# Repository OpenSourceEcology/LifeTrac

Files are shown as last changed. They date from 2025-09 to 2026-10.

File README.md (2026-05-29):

# LifeTrac
Skidded Tractor For Everday Use

This repository contains detailed information about each version of the LifeTrac series, including comprehensive documentation extracted from the Open Source Ecology wiki pages.

## Version Folders

Each LifeTrac version has its own folder containing detailed documentation:

* **[LifeTrac I](LifeTrac-I/)** - 2008 - The first prototype with articulated steering
* **[LifeTrac II](LifeTrac-II/)** - Beginning of modular Power Cube design with skid steering
* **[LifeTrac III](LifeTrac-III/)** - Compact design with single loader and quick attach valves
* **[LifeTrac IV](LifeTrac-IV/)** - Enhanced with larger hydraulic motors and Modular Wheel Units
* **[LifeTrac V](LifeTrac-V/)** - Introduction of LifeTrac Construction Set with 4"x4" tubing
* **[LifeTrac VI](LifeTrac-VI/)** - Refined design with fixed loader arm geometry
* **[LifeTrac VII](LifeTrac-VII/)** - First tracked version for bulldozer applications
* **[LifeTrac v16](LifeTrac-v16/)** - (LifeTrac VIII) 2016 - Simplified traction machine design
* **[Microtrac v17.10](Microtrac-v17.10/)** - (LifeTrac IX) Compact modular design
* **[LifeTrac v17.10](LifeTrac-v17.10/)** - 5 Minute Part Replacement focus
* **[LifeTrac v20.12](LifeTrac-v20.12/)** - Latest version with UTU and UWU systems
* **[LifeTrac v25](LifeTrac-v25/)** - Remote control system with LoRa/MQTT communication (Work in Progress)

## Genealogy

* [LifeTrac I](https://wiki.opensourceecology.org/wiki/LifeTrac_I) - 2008 - Articulated steering, 4 wheel drive, wheel chains, dedicated 55 hp diesel engine. Limited roll-over protection.
* [LifeTrac II](https://wiki.opensourceecology.org/wiki/LifeTrac_II) - Began modular Power Cube design. Skid steering with tracks on rubber tires, 4 wheel drive, 2 modular engine units (Power Cubes), 54 hp total, front- and rear-end loaders included.
* [LifeTrac III](https://wiki.opensourceecology.org/wiki/LifeTrac_III) - Same as II but one single (front-end) loader arm. 32 cu in hydraulic motors. Quick attach valves added.
* [LifeTrac IV](https://wiki.opensourceecology.org/wiki/LifeTrac_IV) - Larger hydraulic motors (45 cu in) were used, and Modular Wheel Units were added. Quick connects added to hydraulic controls.
* [LifeTrac V](https://wiki.opensourceecology.org/wiki/LifeTrac_V) - Began using LifeTrac Construction Set - 4"x4" square tubing, and increased modularity of construction. Modular Wheel Units continued.
* [LifeTrac VI](https://wiki.opensourceecology.org/wiki/LifeTrac_VI) - Continued LifeTrac Construction Set. Modular Wheel Units are a robust design feature. Same design, but fixed the loader arm geometry.
* [LifeTrac VII](https://wiki.opensourceecology.org/wiki/LifeTrac_VII) - First tracked version built. Continuing Tractor Construction Set with Bulldozer Development.
* [LifeTrac v16](https://wiki.opensourceecology.org/wiki/LifeTrac_v16) (LifeTrac VIII) - 2016 - Tracked tractor designed purely as a simplified traction machine with 7000 lb of pull.
* [Microtrac v17.10](https://wiki.opensourceecology.org/wiki/MicroTrac_v17.10) (LifeTrac IX) - In use in 2021 but modified to shorter tracks.
* [LifeTrac v17.10](https://wiki.opensourceecology.org/wiki/LifeTrac_v17.10) - Universal Wheel Unit no longer the main drive option to promote 5 Minute Part Replacement.
* [LifeTrac v20.12](https://wiki.opensourceecology.org/wiki/LifeTrac_v20.12) - Built during Summer X 2021. Includes work on UTU and UWU. Test bed for 5 Minute Part Replacement.
* [LifeTrac v25](https://wiki.opensourceecology.org/wiki/LifeTrac_v25) - Remote control system featuring LoRa/MQTT communication for hydraulic operation control. Includes Arduino Opta controller, ROS2 integration, and web-based interface with live camera feed. (Work in Progress)

## Repository Structure

Each version folder contains:
- **README.md** - Comprehensive overview with technical details and historical significance
- **bill_of_materials.md** - Bill of materials information (where available)

The documentation has been extracted and compiled from the [Open Source Ecology wiki](https://wiki.opensourceecology.org) to provide a comprehensive reference for each LifeTrac version.

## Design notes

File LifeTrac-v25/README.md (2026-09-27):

# LifeTrac v25 - Remote Control System

LifeTrac v25 features a comprehensive remote control system with multiple control modes including WiFi/MQTT and direct Bluetooth (BLE) communication for hydraulic operation control.

## Machine Design

LifeTrac v25 is a remotely-operated compact utility loader designed as an open-source alternative sized between a Toro Dingo and a Bobcat. Built using parametric OpenSCAD design, it features modular construction following Open Source Ecology principles.

### Design Overview

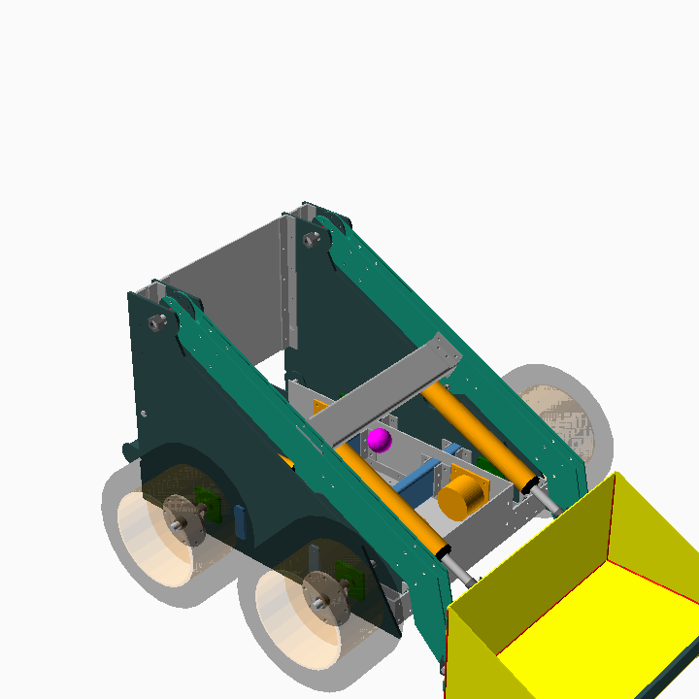
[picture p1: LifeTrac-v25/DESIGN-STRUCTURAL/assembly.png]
LifeTrac v25 Assembly

*3D render of the complete LifeTrac v25 assembly*

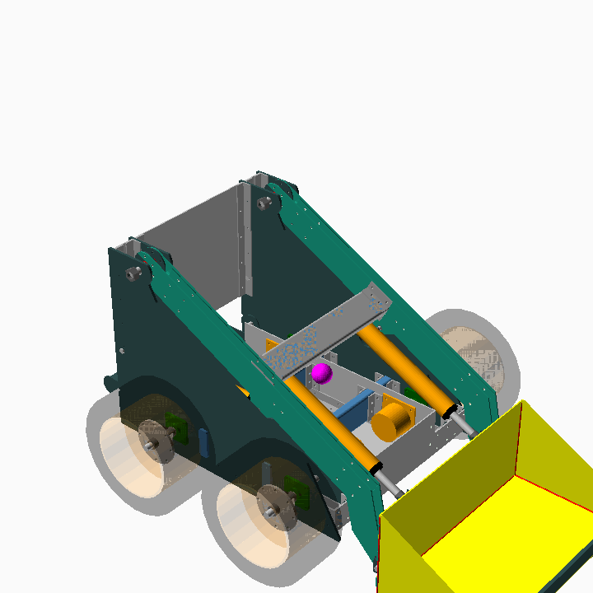
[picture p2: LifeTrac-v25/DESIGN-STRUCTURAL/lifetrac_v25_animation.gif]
LifeTrac v25 Animation

*Animation showing loader arm movement range*

### Key Design Features

- **Modular Construction:** Plate steel, square tubing, and angle iron components for easy fabrication and repair
- **Remote Operation:** No operator seat required, optional standing deck for manual operation
- **Hydraulic Power:** 4 independent wheel motors for all-wheel drive, 2 cylinders for arm lift, 2 for bucket tilt
- **Open Source CAD:** Complete OpenSCAD parametric design files for customization and manufacturing

### Technical Specifications

| Specification | Value (mm) | Value (inches) | Value (meters) |
|---|---|---|---|
| **Overall Width** | 1,200 mm | 47.2" | 1.20 m |
| **Overall Length** | 1,800 mm | 70.9" | 1.80 m |
| **Height to Frame Top** | 1,000 mm | 39.4" | 1.00 m |
| **Ground Clearance** | 150 mm | 5.9" | 0.15 m |
| **Wheel Diameter** | 500 mm | 19.7" | 0.50 m |

### Performance Specifications

| Specification | Value |
|---|---|
| **Hydraulic System Pressure** | 3,000 PSI |
| **Rated Operating Capacity** | See the structural analysis in [STRUCTURAL_ANALYSIS_LOG.md](DESIGN-STRUCTURAL/STRUCTURAL_ANALYSIS_LOG.md) |
| **Drive Configuration** | All-wheel drive (4 hydraulic motors) |
| **Cylinder Bore (Lift)** | 63.5 mm (2.5") |

### Weight Estimate

Machine weight is estimated at **800-1,000 kg (1,760-2,200 lbs)** based on steel construction with:
- 1/4" (6.35mm) plate steel for most components
- 1/2" (12.7mm) plate steel for high-stress areas
- 4"×4"×1/4" square tubing for main frame
- 3"×3"×1/4" square tubing for loader arms

*Note: Weight estimate is a manual calculation based on material specifications. Dimensional specifications in the tables above are automatically extracted from the OpenSCAD design files and updated when the design changes. See [DESIGN-STRUCTURAL/README.md](DESIGN-STRUCTURAL/README.md) for complete design documentation.*

## Features

* **Multiple Control Modes:** switch for MQTT/OFF/BLE mode selection (BLE default)
* **BLE Direct Control:** Direct Bluetooth connection to DroidPad app (no WiFi/broker needed)
* **Remote Joystick Control:** Dual joystick setup for tank steering and hydraulic functions
* **DroidPad Compatible:** Native support for DroidPad via BLE or MQTT
* **WiFi Communication:** Reliable wireless control with MQTT protocol
* **ROS2 Integration:** Control LifeTrac from BeagleBone or any ROS2-enabled device
* **Configurable Flow Control:** Choose between single or dual proportional flow valves via jumper
  - Single valve: Simpler setup, all functions share flow rate (flow is limited by the minimum non-zero joystick input)
  - Dual valve: Independent control, advanced maneuvering with variable turning radius
* **Proportional Flow Control:** Speed regulation based on joystick input intensity
* **Safety Features:** Emergency stop, communication timeout, and fail-safe operation
* **Status Monitoring:** Real-time system status and diagnostics

## Control Scheme

### Tank Steering
- **Left Joystick Y-axis:** Forward/backward movement for both tracks
- **Left Joystick X-axis:** Differential steering (left/right turns)

### Hydraulic Functions  
- **Right Joystick Y-axis:** Arms up/down control
- **Right Joystick X-axis:** Bucket up/down control

### Speed Control
- **Proportional Flow Valve:** Automatically adjusts system speed based on maximum joystick input
- **Deadzone:** 10% deadzone prevents unwanted movements from joystick drift

# Hardware Bill of Materials

## Onboard Controller (LifeTrac)

### Hydraulic Components

| Qty | Item | Description | Unit Price | Total |
|-----|---|---|---|---|
| 4 | Parker Hydraulic Directional Solenoid Valve (D1VW001CNKW) | 21.1 gpm Max Flow Rate, D03 NFPA Size, Three Positions, 12V DC, Closed Center | $314.84  | $1,259.36 |
| | **Purchase:** [Grainger](https://www.grainger.com/product/PARKER-Hydraulic-Directional-Valve-2NMU7) |  |  |  |
| | **Manual:** [Parker D1VW Series Manuals](https://www.manualslib.com/products/Parker-D-1vw-Series-11678625.html) \| [Product Info](https://ph.parker.com/ca/en/product/directional-control-valve-series-d1vw-d1vw-ee/d1vw001cnkw) |  |  |  |
| 8 | Hirschmann DIN Connector (5100-1080000) | Standard hydraulic valve connectors | $7.95 | $63.60 |
| | **Purchase:** [Surplus Center](https://www.surpluscenter.com/Hydraulics/Hydraulic-Valves/Solenoid-Valves/Hirschmann-Connector-5100-1080000-11-2457.axd) |  |  |  |
| |  |  | **Subtotal:** | **$1,322.96** |

### Manifold Subplates

**Option A - For dual proportional valve setup:**

| Qty | Item | Description | Unit Price | Total |
|-----|---|---|---|---|
| 2 | 2 Station D03 Parallel CC Manifold Subplate | For dual valve configuration | $90.00 | $180.00 |
| | | **Purchase:** [Surplus Center](https://www.surpluscenter.com/Hydraulics/Hydraulic-Adapters-Fittings/Subplates-Cover-Plates-Manifolds/2-Station-D03-Parallel-CC-Manifold-Subplate-SFP-10002-9-4070-2.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) | | |
| | | | **Subtotal:** | **$180.00** |

**Option B - For single and no proportional valve setup:**

| Qty | Item | Description | Unit Price | Total |
|-----|---|---|---|---|
| 1 | 4 Station D03 Parallel CC Manifold Subplate | For single or no valve configuration | $183.00 | $183.00 |
| | | **Purchase:** [Surplus Center](https://www.surpluscenter.com/Hydraulics/Hydraulic-Adapters-Fittings/Subplates-Cover-Plates-Manifolds/4-Station-D03-Parallel-CC-Manifold-Subplate-SFP10004-9-4070-4.a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) | | |
| | | | **Subtotal:** | **$183.00** |

### Flow Control Valves

**Option A - Single Valve Configuration (Basic):**

| Qty | Item | Description | Unit Price | Total |
|-----|---|---|---|---|
| 1 | Brand Hydraulics PEFC12-20 Electronically Adjustable Proportional Flow Control Valve | 0-20 GPM, 3000 PSI. For basic configuration | $449.99 | $449.99 |
| | | **Purchase:** [Northern Tool](https://www.northerntool.com/products/brand-hydraulics-electronically-adjustable-flow-control-valve-0-20-gpm-3-000-psi-model-pefc12-20-12-20166) \| [Motion](https://www.motion.com/products/sku/11364850) | | |
| | | **Manual:** [Installation & User Guide (PDF)](https://www.brand-hyd.com/wfdata/files/install/valves/EFC-Installation-Sheet-09-24.pdf) \| [Product Info](https://www.brand-hyd.com/Products/Valves/Flow_Controls/EFC/) | | |
| 1 | Burkert 8605 Type 316532 Flow Valve Controller | PWM control electronics for proportional valves | $319.50 | $319.50 |
| | | **Purchase:** [Valves Direct](https://www.valves-direct.com/burkert-new-products/114143-burkert-316532-type-8605-g-kl-e-f-00-q-b.html) \| [RS Components](https://us.rs-online.com/product/burkert-fluid-control-systems/316532/74474892/) | | |
| | | **Manual:** [Type 8605 Manual (PDF)](https://www.burkert.com/en/content/download/287474/file/MA8605-Manual-EU-EN.pdf) \| [Product Info](https://www.burkert.com/en/products/316532) | | |
| | | | **Subtotal:** | **$769.49** |

**Option B - Dual Valve Configuration (Advanced Maneuvering):**

| Qty | Item | Description | Unit Price | Total |
|-----|---|---|---|---|
| 2 | Brand Hydraulics PEFC12-20 Electronically Adjustable Proportional Flow Control Valve | 0-20 GPM, 3000 PSI. For advanced maneuvering with independent flow control | $449.99 | $899.98 |
| | | **Purchase:** [Northern Tool](https://www.northerntool.com/products/brand-hydraulics-electronically-adjustable-flow-control-valve-0-20-gpm-3-000-psi-model-pefc12-20-12-20166) \| [Motion](https://www.motion.com/products/sku/11364850) | | |
| | | **Manual:** [Installation & User Guide (PDF)](https://www.brand-hyd.com/wfdata/files/install/valves/EFC-Installation-Sheet-09-24.pdf) \| [Product Info](https://www.brand-hyd.com/Products/Valves/Flow_Controls/EFC/) | | |
| 2 | Burkert 8605 Type 316532 Flow Valve Controller | PWM control electronics for proportional valves | $319.50 | $639.00 |
| | | **Purchase:** [Valves Direct](https://www.valves-direct.com/burkert-new-products/114143-burkert-316532-type-8605-g-kl-e-f-00-q-b.html) \| [RS Components](https://us.rs-online.com/product/burkert-fluid-control-systems/316532/74474892/) | | |
| | | **Manual:** [Type 8605 Manual (PDF)](https://www.burkert.com/en/content/download/287474/file/MA8605-Manual-EU-EN.pdf) \| [Product Info](https://www.burkert.com/en/products/316532) | | |
| | | | **Subtotal:** | **$1,538.98** |

*Note: See DESIGN-HYDRAULIC/FLOW_VALVE_CONFIGURATION.md for single vs dual valve configuration details*

### Arduino Controllers

| Qty | Item | Description | Unit Price | Total |
|-----|---|---|---|---|
| 1 | Arduino Opta WiFi | Main controller board | $199.00 | $199.00 |
| | | **Purchase:** [Arduino Store](https://store.arduino.cc/products/opta-wifi) | | |
| | | **Documentation:** [Arduino Opta Docs](https://docs.arduino.cc/hardware/opta) | | |
| 1 | Arduino Pro Opta Ext D1608S | Digital I/O expansion (16 digital inputs, 8 solid state outputs) | $151.00 | $151.00 |
| | | **Purchase:** [Arduino Store](https://store.arduino.cc/products/opta-ext-d1608s) | | |
| 1 | Arduino Pro Opta Ext A0602 | Analog I/O expansion (6 analog inputs, 2 analog outputs) | $229.00 | $229.00 |
| | | **Purchase:** [Arduino Store](https://store.arduino.cc/products/opta-ext-a0602) | | |
| | | | **Subtotal:** | **$579.00** |

## Remote Control Unit

| Qty | Item | Description | Unit Price | Total |
|-----|---|---|---|---|
| 2 | SparkFun Qwiic Joystick (COM-15168) | Dual joystick controllers with I2C interface | $12.50 | $25.00 |
| | | **Purchase:** [SparkFun](https://www.sparkfun.com/products/15168) \| [DigiKey](https://www.digikey.com/en/products/detail/sparkfun-electronics/15168/9953917) | | |
| | | **Guide:** [Hookup Guide](https://learn.sparkfun.com/tutorials/qwiic-joystick-hookup-guide) | | |
| 1 | SparkFun Thing Plus - ESP32 WROOM (USB-C) (DEV-20168) | Remote control microcontroller with WiFi/BLE | $33.73 | $33.73 |
| | | **Purchase:** [SparkFun](https://www.sparkfun.com/products/20168) \| [DigiKey](https://www.digikey.com/en/products/detail/sparkfun-electronics/20168/16688100) | | |
| | | **Guide:** [Product Documentation](https://learn.sparkfun.com/tutorials/sparkfun-thing-plus-esp32-wroom-usb-c-hookup-guide) | | |
| 1 | Enclosure for handheld remote control | Custom or off-the-shelf enclosure | $35.00 | $35.00 |
| 1 | Li-Po battery pack with charging circuit | 3.7V Li-Po battery with USB charging | $20.00 | $20.00 |
| | | | **Subtotal:** | **$113.73** |

## MQTT Broker & Web Controller Infrastructure

| Qty | Item | Description | Unit Price | Total |
|-----|---|---|---|---|
| 1 | Raspberry Pi 4 Model B (4GB) | 4GB+ RAM recommended for Mosquitto MQTT broker and web interface | $55.00 | $55.00 |
| | | **Purchase:** [PiShop](https://www.pishop.us/product/raspberry-pi-4-model-b-4gb/) \| [Authorized Resellers](https://www.raspberrypi.com/products/raspberry-pi-4-model-b/) | | |
| | | **Software:** [Mosquitto MQTT Broker](https://github.com/eclipse-mosquitto/mosquitto) | | |
| 1 | SanDisk Ultra MicroSD Card (32GB) | Class 10, minimum 32GB recommended | $8.99 | $8.99 |
| | | **Purchase:** [Amazon](https://www.amazon.com/micro-sd-card-32gb/s?k=micro+sd-card+32gb) | | |
| 1 | eero 6 Dual-Band Mesh Wi-Fi 6 Router | WiFi 6 mesh router with coverage up to 1,500 sq ft | $89.99 | $89.99 |
| | | **Purchase:** [Best Buy](https://www.bestbuy.com/product/eero-6-dual-band-mesh-wi-fi-6-router-1-pack-white/J39QV832QV) \| [Amazon](https://www.amazon.com/Amazon-eero-6-mesh-Wi-Fi-6-router/dp/B085VM9ZDD) | | |
| | | **Alternative:** [eero 6+ (faster, $139.99)](https://www.amazon.com/Amazon-eero-Wi-Fi-router-newest/dp/B08ZK39NSL) | | |
| 1 | Arducam IMX335 Camera Module (5MP) | Low-light camera for web interface live feed | $33.99 | $33.99 |
| | | **Purchase:** [Amazon](https://www.amazon.com/Arducam-Raspberry-15-15pin-15-22pin-Included/dp/B0FG6W8HC9) \| [RobotShop](https://www.robotshop.com/products/arducam-imx335-mipi-camera-module-rpi) | | |
| | | **Documentation:** [Arducam IMX335 Docs](https://docs.arducam.com/Raspberry-Pi-Camera/Native-camera/5MP-IMX335) | | |
| 1 | Camera cable | 15-pin to 15-pin or 15-pin to 22-pin (included with Arducam) | Included | $0.00 |
| | | | **Subtotal:** | **$187.97** |

---

### Grand Total

| Configuration | Components | Total |
|---|---|---|
| **Base System** (without flow valves, remote, or web infrastructure) | Hydraulic Components + Manifold + Arduino Controllers | **$2,081.96** (Option A) or **$2,084.96** (Option B) |
| **Base + Single Flow Valve** | Base System + 1 Flow Control Valve + 1 Controller | **$2,851.45** (Option A) or **$2,854.45** (Option B) |
| **Base + Dual Flow Valves** | Base System + 2 Flow Control Valves + 2 Controllers | **$3,620.94** (Option A) or **$3,623.94** (Option B) |
| **Complete - Single Valve** | Base + Single Flow Valve + Remote Unit + Infrastructure | **$3,153.15** (Option A) or **$3,156.15** (Option B) |
| **Complete - Dual Valves** | Base + Dual Flow Valves + Remote Unit + Infrastructure | **$3,922.64** (Option A) or **$3,925.64** (Option B) |

**Configuration Notes:**
- **Option A (Manifold)**: 2-station manifold for dual proportional valve setup ($180.00)
- **Option B (Manifold)**: 4-station manifold for single/no proportional valve setup ($183.00)
- **Single Valve**: Basic configuration suitable for most applications
- **Dual Valves**: Advanced maneuvering with independent flow control and variable turning radius

*Note: Prices are subject to change. Check vendor websites for current pricing. Total does not include shipping, taxes, or additional hardware like hydraulic hoses, fittings, and mounting hardware.*

# Software Components

## Arduino Code
- **DESIGN-CONTROLLER/arduino_opta_controller/**: Main controller code for Arduino Opta
- **DESIGN-CONTROLLER/esp32_remote_control/**: Remote control code for ESP32

## Raspberry Pi Web Controller
- **DESIGN-CONTROLLER/raspberry_pi_web_controller/**: Browser-based control with live video feed
  - Live camera streaming from Arducam IMX335 using libcamera
  - Touch-enabled on-screen joysticks for phone/tablet control
  - Keyboard shortcuts for desktop control
  - WebSocket for real-time communication
  - See [DESIGN-CONTROLLER/raspberry_pi_web_controller/README.md](DESIGN-CONTROLLER/raspberry_pi_web_controller/README.md) for setup

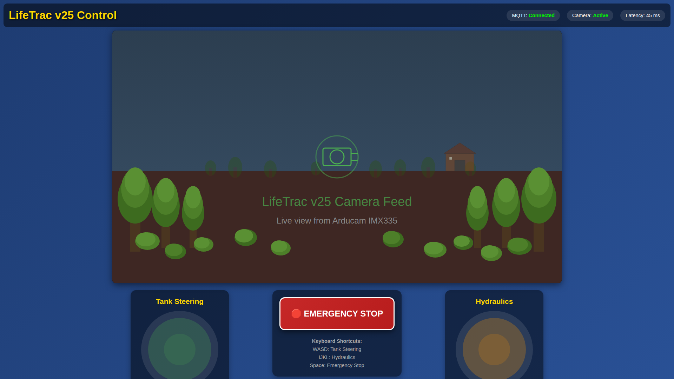
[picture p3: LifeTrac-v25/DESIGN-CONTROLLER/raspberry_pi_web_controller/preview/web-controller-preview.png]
Web Controller Preview

*Browser-based control interface with live camera feed and on-screen joysticks*

## ROS2 Integration
- **DESIGN-CONTROLLER/ros2_bridge/**: ROS2 packages for BeagleBone control via MQTT
  - **lifetrac_msgs/**: Custom ROS2 message definitions
  - **lifetrac_mqtt_bridge/**: Bridge node using mqtt_client package
  - See [DESIGN-CONTROLLER/ros2_bridge/README.md](DESIGN-CONTROLLER/ros2_bridge/README.md) for complete ROS2 setup

## Configuration Files
- **config/**: MQTT broker and WiFi configuration files
- **DESIGN-CONTROLLER/arduino_libraries.txt**: Required Arduino libraries

## Documentation
- **DESIGN-CONTROLLER/INSTALLATION_GUIDE.md**: Complete setup and installation instructions
- **DESIGN-HYDRAULIC/FLOW_VALVE_CONFIGURATION.md**: Proportional flow valve configuration (single vs dual valve)
- **DESIGN-KINEMATICS/README.md**: Motion command semantics — input mapping, differential mixing, ramp profiles, reversal handling, flow budgeting, and the build-variant × motion-primitive matrix
- **DROIDPAD_INTEGRATION.md**: Guide for DroidPad integration via BLE or MQTT
- **DROIDPAD_BLE_SETUP.md**: Step-by-step BLE direct control setup for DroidPad
- **MODE_SWITCH_WIRING.md**: Hardware switch wiring for MQTT/OFF/BLE selection
- **DESIGN-CONTROLLER/WIRING_DIAGRAM.md**: Detailed wiring and connection diagrams
- **DESIGN-HYDRAULIC/HYDRAULIC_DIAGRAM.md**: ASCII hydraulic system diagram showing component layout
- **DESIGN-CONTROLLER/ros2_bridge/README.md**: ROS2 integration and BeagleBone setup guide
- **DESIGN-CONTROLLER/raspberry_pi_web_controller/README.md**: Web interface setup and usage guide

## Testing Tools
- **DESIGN-CONTROLLER/test_scripts/**: MQTT testing and debugging utilities

# Quick Start

## Option 1: DroidPad via BLE (Simplest - Recommended for Mobile)
1. **Program Arduino Opta:** Upload controller code with BLE support
2. **Set Mode:** Set mode switch to BLE position (or leave switch uninstalled for default BLE)
3. **Connect DroidPad:** Open DroidPad app, scan for "LifeTrac-v25" via Bluetooth
4. **Configure:** Set up BLE characteristics using provided UUIDs
5. **Control:** Start controlling immediately - no WiFi/network needed!

For detailed instructions, see [DROIDPAD_BLE_SETUP.md](DESIGN-CONTROLLER/DROIDPAD_BLE_SETUP.md).

## Option 2: Raspberry Pi Web Controller (Best for Fixed Installation)
1. **Set up MQTT Broker:** Install Mosquitto on Raspberry Pi using DESIGN-CONTROLLER/config/mosquitto.conf
2. **Program Arduino Opta:** Upload controller code
3. **Set Mode:** Set mode switch to MQTT position
4. **Install Web Controller:** Run `sudo ./install.sh` in DESIGN-CONTROLLER/raspberry_pi_web_controller/
5. **Connect Camera:** Attach Arducam IMX335 to Raspberry Pi
6. **Access Interface:** Open `http://<raspberry-pi-ip>:5000` in any browser

For detailed instructions, see [DESIGN-CONTROLLER/raspberry_pi_web_controller/README.md](DESIGN-CONTROLLER/raspberry_pi_web_controller/README.md).

## Option 3: ESP32 Handheld Remote Control
1. **Set up MQTT Broker:** Install Mosquitto on Raspberry Pi using DESIGN-CONTROLLER/config/mosquitto.conf
2. **Program Controllers:** Upload Arduino code to Opta and ESP32 boards
3. **Set Mode:** Set mode switch to MQTT position
4. **Configure Network:** Update WiFi credentials and MQTT settings in code
5. **Wire System:** Follow DESIGN-CONTROLLER/WIRING_DIAGRAM.md for all connections
6. **Test System:** Use DESIGN-CONTROLLER/test_scripts/mqtt_test.py for validation

For detailed instructions, see [DESIGN-CONTROLLER/INSTALLATION_GUIDE.md](DESIGN-CONTROLLER/INSTALLATION_GUIDE.md).

## Option 4: ROS2 Control from BeagleBone
1. **Set up MQTT Broker:** Same as above
2. **Program Arduino Opta:** Upload controller code
3. **Set Mode:** Set mode switch to MQTT position
4. **Install ROS2 on BeagleBone:** Follow ROS2 installation guide
5. **Build ROS2 packages:** Build lifetrac_msgs and lifetrac_mqtt_bridge
6. **Launch bridge:** `ros2 launch lifetrac_mqtt_bridge lifetrac_bridge.launch.py`

For detailed ROS2 instructions, see [DESIGN-CONTROLLER/ros2_bridge/README.md](DESIGN-CONTROLLER/ros2_bridge/README.md).

# Safety Features

- **Communication Timeout:** All movement stops if no commands received within 1 second
- **Emergency Stop:** Serial command or communication loss triggers immediate stop
- **Fail-Safe Operation:** Valves return to neutral position on power loss
- **Status Monitoring:** Real-time diagnostics and connection status

# Development Status

✅ **Completed:**
- Arduino Opta controller code with MQTT integration
- ESP32 remote control with dual joystick support  
- Proportional flow control implementation
- Safety systems and emergency stop functionality
- Complete installation and wiring documentation
- MQTT test utilities for debugging
- ROS2 integration packages for BeagleBone control
- Custom ROS2 message definitions for control commands
- Bridge using mqtt_client for ROS2-MQTT communication
- **Raspberry Pi web controller with live video feed and browser-based joysticks**

🔄 **In Progress:**
- Field testing and calibration

# External Links

- [Arduino Opta Documentation](https://docs.arduino.cc/hardware/opta)
- [SparkFun Qwiic Joystick Guide](https://learn.sparkfun.com/tutorials/qwiic-joystick-hookup-guide)
- [Eclipse Mosquitto MQTT Broker](https://mosquitto.org/)
- [Arducam IMX335 Documentation](https://docs.arducam.com/Raspberry-Pi-Camera/Native-camera/5MP-IMX335)
- [Raspberry Pi libcamera Guide](https://www.raspberrypi.com/documentation/computers/camera_software.html)

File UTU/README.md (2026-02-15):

# Universal Track Unit (UTU)

The Universal Track Unit (UTU) is an interchangeable traction module designed to work interchangeably with the Universal Wheel Unit (UWU).

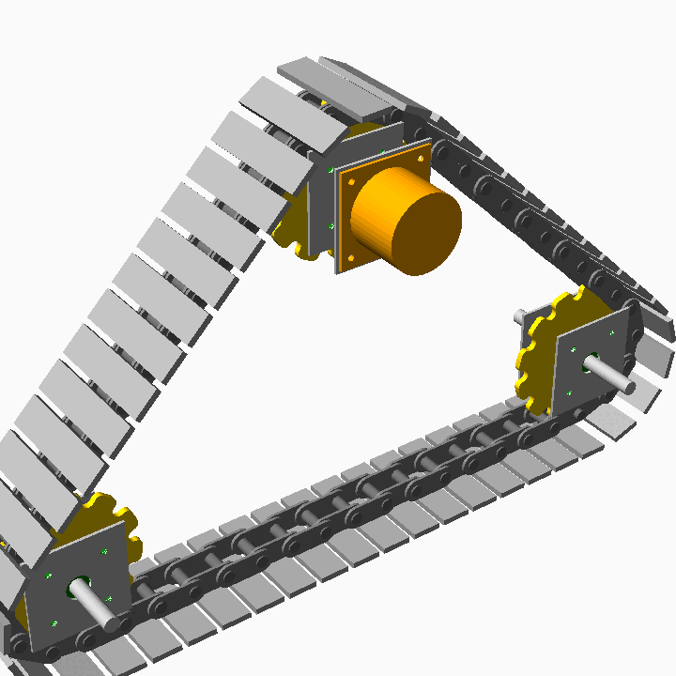
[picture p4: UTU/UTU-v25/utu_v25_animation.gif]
UTU v25 Animation


## References
- [Universal Track Unit Wiki](https://wiki.opensourceecology.org/wiki/Universal_Track_Unit)

## Integration
We want to have the option to use either the UWU or UTU for the LifeTrac v25.

The design goal is to be able to give a coordinate on any future machine and define the three plates and the unit size, so that the UWU or UTU can be adopted for use in place.

## UTU v25 Specifications

The v25 iteration of the UTU is designed with the following parameters (Source: `UTU-v25/utu_v25.scad`):

### Layout
- **Topology:** 3-axis triangular system (configurable via `num_axes`).
- **Bottom Idlers:** 2 idler axes, 4 feet apart (`idler_spacing = 48"`).
- **Drive Axis:** 1 powered axis, 2 feet above idlers, centered horizontally.
- **Front Idler Adjustment:** Automatically shifts along X to make total chain length an integer multiple of chain pitch.

### Structure (shared with UWU)
- **Plates:** 8" x 8" x 0.25" Steel Plates.
- **Bearing Spacing:** 4.0" between bearing plates.
- **Motor Mount to Bearing:** 3.0" spacing.

### Bearing Mounts
- **Bearing Type:** 4-bolt Flange Bearing.
- **Housing:** Ø2.5", 0.75" protrusion, 0.5" flange.
- **Mounting Pattern:** 4-bolt, Ø6.19" BCD, 45° orientation.
- **Center Clearance:** Ø2.00".

### Motor Mount (Drive Axis)
- **Motor Body:** Ø6.0" x 5.0".
- **Motor Flange:** 7.5" x 7.5" Square, 0.5" thick.
- **Motor Shaft:** Ø1.0" x 1.5".
- **Mounting Pattern:** 4-bolt, Ø8.25" BCD, 45° orientation.
- **Coupling:** Ø2.0" x 2.0".

### Drivetrain
- **Shaft:** Ø1.25" x 14.0" length.
- **Shaft Collars:** Ø2.0" x 0.75", sandwiching each sprocket.

### Track Chain
- **Style:** Chainsaw-chain staggered links (alternating inner/outer connector plates).
- **Track Bars (Feet):** 2.5" x 0.5" x 10" steel bar.
- **Connecting Rods:** Ø1.0" steel rods.
- **Chain Pitch:** 3.0" (bar width + 0.5" gap).
- **Rod Hole Clearance:** 1 mm diametral.

### Connector Plates
- **Height:** 2.0" above bar surface.
- **Thickness:** 0.25".
- **Width:** One chain pitch (3.0").
- **Inner Plate Offset:** Derived from 2.0" face-to-face gap.
- **Outer Plate Offset:** Derived from inner offset + 1/8" stagger gap.
- **Rod Pads:** Circular pads (union) at each rod hole location.

### Sprocket
- **Type:** Custom chain sprocket with filleted tooth roots.
- **Teeth:** 12.
- **Pitch Radius:** Derived from chain pitch via `P / (2 × sin(180/N))`.
- **Root Circle:** Sized to sit on track bar surface.
- **Tip Radius:** Pitch radius + rod seat radius.
- **Thickness:** 0.5".
- **Fillets:** Rod radius at tooth roots (offset-based).
- **Phase:** Per-sprocket rotation computed from chain path geometry.

### Chain Path (Parametric)
- **Total Length:** Automatically computed (straight spans + sprocket arc wraps).
- **Link Count:** Rounded to nearest integer (`num_chain_links`).
- **Front Idler Adjustment:** Newton-method shift so chain = integer × pitch.
- **Path Function:** `chain_point(s)` returns `[x, z, angle]` for any cumulative position.
- **Wrap Angles:** Computed per-sprocket from tangent contact geometry.

### CAD Files
- **OpenSCAD:** `UTU-v25/utu_v25.scad` (Parametric source).
- **Gear Library:** `UTU-v25/gears.scad` (chrisspen/gears, CC BY-NC-SA).

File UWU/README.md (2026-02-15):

# Universal Wheel Unit (UWU)

The Universal Wheel Unit (UWU) is a standardized system of bearings and motors mounted to three parallel plates.

## References
- [Universal Wheel Unit Wiki](https://wiki.opensourceecology.org/wiki/Universal_Wheel_Unit)
- [Quick Connect Wheels Wiki](https://wiki.opensourceecology.org/wiki/Quick_Connect_Wheels)

## Integration
We want to have the option to use either the UWU or UTU (Universal Track Unit) for the LifeTrac v25.

The design goal is to be able to give a coordinate on any future machine and define the three plates and the UWU size, so that the UWU or UTU can be adopted for use in place. Both units share the same plate dimensions, bolt patterns, and bearing/motor mounting interfaces.

## UWU v25 Specifications

The v25 iteration of the UWU is designed with the following parameters (Source: `UWU-v25/uwu_v25.scad`):

### Structure
- **Plates:** Three 8" x 8" x 0.25" Steel Plates.
- **Spacing:**
  - Motor Mount Plate to First Bearing Plate: 3.0"
  - First Bearing Plate to Second Bearing Plate: 4.0"

### Motor Mount (Plate 1)
- **Motor Body:** Ø6.0"
- **Motor Flange:** 7.5" x 7.5" Square.
- **Mounting Pattern:** 4-bolt, Ø8.25" Bolt Circle Diameter (4.125" radius), rotated 45° to fit corners.
- **Center Pilot:** Ø2.00"

### Bearing Mounts (Plate 2 & 3)
- **Bearing Type:** 4-bolt Flange Bearing.
- **Housing:** Ø2.5"
- **Mounting Pattern:** 4-bolt, Ø6.19" Bolt Circle Diameter (Derived from QC Wheel fabrication diagrams).
- **Center Clearance:** Ø2.00"

### Drivetrain
- **Shaft:** Ø1.25" x 10.0" Length.
- **Coupling:** Ø2.0" x 2.0" Length connecting Motor Shaft to Main Shaft.

### Compatibility with UTU
The UWU shares its plate dimensions, bolt patterns, bearing mounts, and motor mount interface with the UTU (Universal Track Unit). See `../UTU/README.md` for the track unit specifications.

### CAD Files
- **OpenSCAD:** `UWU-v25/uwu_v25.scad` (Parametric source).
- **FreeCAD Script:** `UWU-v25/generate_uwu_freecad.py` (Generator script).

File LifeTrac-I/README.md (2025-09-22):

# LifeTrac I

**Year:** 2008  
**Alternative Name:** First LifeTrac Prototype  
**Wiki Reference:** [LifeTrac I](https://wiki.opensourceecology.org/wiki/LifeTrac_I)

## Overview

This is the first prototype of the LifeTrac - completed in September, 2008. It was OSE's first attempt to make a riding tractor using articulated steering. The LifeTrac I featured:

- Articulated steering
- 4 wheel drive
- Wheel chains
- Dedicated 55 hp diesel engine
- Limited roll-over protection

## Key Features

- **Steering System:** Articulated steering mechanism
- **Drive System:** 4 wheel drive configuration
- **Traction:** Wheel chains for improved grip
- **Power Plant:** Dedicated 55 hp diesel engine
- **Safety:** Limited roll-over protection

## Historical Significance

The LifeTrac I represents the beginning of Open Source Ecology's modular tractor design journey. This prototype established the foundation for the subsequent development of the LifeTrac series, beginning the exploration of modular, open-source agricultural machinery.

## Status

This is a historical prototype that led to the development of improved versions with enhanced modularity and design features.

## External Links

- [LifeTrac I Blog Post](https://www.opensourceecology.org/lifetrac-continued/)
- [OSE Wiki Page](https://wiki.opensourceecology.org/wiki/LifeTrac_I)

## Next Version

See [LifeTrac II](../LifeTrac-II/README.md) for the next iteration in the series.

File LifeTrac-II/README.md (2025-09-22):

# LifeTrac II

**Alternative Name:** Second LifeTrac Prototype  
**Wiki Reference:** [LifeTrac II](https://wiki.opensourceecology.org/wiki/LifeTrac_II)

## Overview

The LifeTrac II was a departure from the articulated steering design in LifeTrac I to a skid steer design. This version began the modular Power Cube design that became a hallmark of the LifeTrac series. The tractor is powered by 2 Power Cubes and has 2 loaders - both on the front and on the rear of the tractor.

## Key Features

- **Steering System:** Skid steering with tracks on rubber tires
- **Drive System:** 4 wheel drive
- **Power Plant:** 2 modular engine units (Power Cubes), 54 hp total
- **Attachments:** Front-end and rear-end loaders included
- **Design Philosophy:** Beginning of modular Power Cube design

## Design Rationale

The change from articulated to skid steer design was made for several advantages:
- Greater lifting capacities
- Tighter steering in confined spaces  
- Greater flexibility on lift height
- Wider range of tool attachments

**Trade-off:** Skid steer style tractors are much harder on the ground than articulated steering tractors.

## Historical Significance

LifeTrac II marks the beginning of the modular Power Cube design philosophy that would influence all subsequent LifeTrac versions. This represented a major evolution from the single-engine design of LifeTrac I.

## External Links

- [OSE Wiki Page](https://wiki.opensourceecology.org/wiki/LifeTrac_II)

## Navigation

- **Previous:** [LifeTrac I](../LifeTrac-I/README.md)
- **Next:** [LifeTrac III](../LifeTrac-III/README.md)

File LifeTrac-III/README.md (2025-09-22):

# LifeTrac III

**Alternative Name:** Third LifeTrac Iteration  
**Wiki Reference:** [LifeTrac III](https://wiki.opensourceecology.org/wiki/LifeTrac_III)

## Overview

LifeTrac III is the third iteration of the LifeTrac series. It closely matches LifeTrac II, but with significant modifications:
- 18" shorter overall length
- Single (front-end) loader arm instead of dual loaders
- 32 cu in hydraulic motors
- Quick attach valves added

## Key Features

- **Design Base:** Modified LifeTrac II design
- **Size:** Compact design - 18" shorter than LifeTrac II
- **Loader Configuration:** Single front-end loader arm
- **Hydraulic Motors:** 32 cu in hydraulic motors
- **Hydraulic System:** Quick attach valves for improved functionality
- **Construction:** Same skid steer design philosophy as LifeTrac II

## Design Status (as of 2011)

- Several prototypes have been built and tested
- Comprehensive documentation available as part of Civilization Starter Kit DVD v0.01
- Bill of Materials created (completeness under review)
- Testing revealed need for LifeTrac IV to address safety concerns and improve capabilities

## Documentation Resources

The LifeTrac III is extensively documented in the Civilization Starter Kit DVD v0.01:

- 4.1 Tractor Design Rationale, Product Ecology
- 4.2 Tractor Master CAD File
- 4.3 Tractor Bill of Materials
- 4.3-4.4 Tractor Fabrication Manual
- 4.5 Tractor Assembly (full assembly video - 12 min)
- 4.6 Tractor Fabrication Drawings
- 4.7 Tractor User Manual
- 4.8 Quality Control Checklist

## Historical Significance

LifeTrac III represents the refinement of the modular Power Cube concept with improved hydraulic systems and more compact design. The lessons learned from this version directly informed the development of LifeTrac IV.

## External Links

- [OSE Wiki Page](https://wiki.opensourceecology.org/wiki/LifeTrac_III)
- [3D Model on GrabCAD](http://grabcad.com/library/life-traciv-lt3-76inch-long)

## Navigation

- **Previous:** [LifeTrac II](../LifeTrac-II/README.md)
- **Next:** [LifeTrac IV](../LifeTrac-IV/README.md)

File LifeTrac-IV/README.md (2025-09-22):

# LifeTrac IV

**Year:** 2012  
**Alternative Name:** Fourth LifeTrac Iteration  
**Wiki Reference:** [LifeTrac IV](https://wiki.opensourceecology.org/wiki/LifeTrac_IV)

## Overview

LifeTrac IV is the fourth iteration of the LifeTrac series, representing a retrofit of existing LifeTrac III units with significant improvements. This version introduces key innovations that would influence future designs.

## Key Features

- **Frame:** Identical to LifeTrac III
- **Hydraulic Motors:** Larger 45 cu in hydraulic motors (upgraded from 32 cu in)
- **Wheel System:** Modular Wheel Units with Quick Connect Wheels
- **Loader Arms:** Bent Loader Arms for improved geometry
- **Hydraulic Controls:** Quick connects added to hydraulic controls
- **Load Capacity:** Additional load carrying capacity from rear weight addition

## Major Improvements from LifeTrac III

### 1. Quick Connect Wheels
- Modular wheel attachment system
- Improved maintenance and part replacement
- Enhanced field serviceability

### 2. Bent Loader Arms
- Improved loader arm geometry
- Better loading and lifting characteristics
- Enhanced operational efficiency

### 3. Larger Hydraulic Motors
- Upgraded from 32 cu in to 45 cu in hydraulic motors
- Increased power and torque capability
- Better performance under load

### 4. Quick Connect Hydraulics
- Quick connects added to hydraulic controls
- Simplified operation and maintenance
- Enhanced modularity

## Development History

- **Last Updated:** September 9, 2012
- **Design Assistance:** GrabCAD community helped with wheel redesign
- **International Application:** Guatemala Team built LifeTrac IV with Power Cube system
- **Design Philosophy:** Retrofit approach to upgrade existing LifeTrac III units

## Historical Significance

LifeTrac IV introduced the Modular Wheel Units concept and Quick Connect systems that became fundamental to the LifeTrac philosophy of modular, serviceable design. The bent loader arms solved geometry issues from previous versions.

## External Links

- [OSE Wiki Page](https://wiki.opensourceecology.org/wiki/LifeTrac_IV)
- [GrabCAD Wheel Design Challenge](http://grabcad.com/challenges/lifetrac-quick-connect-wheels)
- [Guatemala Build Log](https://wiki.opensourceecology.org/wiki/Guatemala_Log)

## Navigation

- **Previous:** [LifeTrac III](../LifeTrac-III/README.md)
- **Next:** [LifeTrac V](../LifeTrac-V/README.md)

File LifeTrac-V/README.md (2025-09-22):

# LifeTrac V

**Alternative Name:** Fifth LifeTrac Iteration  
**Wiki Reference:** [LifeTrac V](https://wiki.opensourceecology.org/wiki/LifeTrac_V)

## Overview

LifeTrac V represents a significant milestone in the LifeTrac series as it began using the LifeTrac Construction Set philosophy. This version marked the standardization of construction methods and increased modularity that would define future LifeTrac designs.

## Key Features

- **Construction Standard:** Began using LifeTrac Construction Set with 4"x4" square tubing
- **Modularity:** Increased modularity of construction
- **Wheel System:** Modular Wheel Units continued from LifeTrac IV
- **Design Philosophy:** Standardized construction methods for easier replication

## Innovation: LifeTrac Construction Set

The introduction of the LifeTrac Construction Set was a major advancement:
- **Material Standard:** 4"x4" square tubing as primary structural element
- **Modularity:** Enhanced modular design for easier assembly and maintenance
- **Standardization:** Consistent construction methods across components
- **Replicability:** Simplified design for easier reproduction by other builders

## Design Evolution

LifeTrac V built upon the successful innovations of LifeTrac IV while introducing:
- Standardized construction methodology
- Enhanced modularity through the Construction Set approach
- Continued use of Modular Wheel Units
- Improved design consistency

## Historical Significance

This version established the LifeTrac Construction Set philosophy using 4"x4" square tubing, which became a foundational element for subsequent designs. The focus on modular construction made the design more accessible to builders worldwide.

## External Links

- [OSE Wiki Page](https://wiki.opensourceecology.org/wiki/LifeTrac_V)

## Navigation

- **Previous:** [LifeTrac IV](../LifeTrac-IV/README.md)
- **Next:** [LifeTrac VI](../LifeTrac-VI/README.md)

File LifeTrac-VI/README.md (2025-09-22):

# LifeTrac VI

**Alternative Name:** Sixth LifeTrac Iteration  
**Status:** In active use (as of 2019)  
**Wiki Reference:** [LifeTrac VI](https://wiki.opensourceecology.org/wiki/LifeTrac_VI)

## Overview

LifeTrac VI continued the LifeTrac Construction Set philosophy established in LifeTrac V. This version represents a refinement of the modular design with robust Modular Wheel Units as a key design feature. A significant improvement was made to the loader arm geometry, fixing issues from previous versions.

## Key Features

- **Construction:** Continued LifeTrac Construction Set with 4"x4" square tubing
- **Modularity:** Modular Wheel Units as a robust design feature
- **Loader Arms:** Fixed loader arm geometry from previous versions
- **Design:** Same overall design as LifeTrac V with improved geometry
- **Status:** Proven design in active use

## Design Improvements

### Loader Arm Geometry
- Fixed loader arm geometry issues from previous versions
- Improved loading and operational characteristics
- Enhanced reliability and performance

### Modular Wheel Units
- Robust implementation of the modular wheel concept
- Reliable field performance
- Proven design for long-term use

## Operational Status

As of 2019, LifeTrac VI remains in active use, demonstrating the reliability and effectiveness of the design improvements made in this iteration.

## Historical Significance

LifeTrac VI represents the maturation of the LifeTrac Construction Set approach with proven modular components. The successful resolution of loader arm geometry issues in this version established design principles that influenced future developments.

## External Links

- [OSE Wiki Page](https://wiki.opensourceecology.org/wiki/LifeTrac_VI)
- [LifeTrac VI Video](https://www.youtube.com/embed/gXP01bjIwHo)

## Navigation

- **Previous:** [LifeTrac V](../LifeTrac-V/README.md)
- **Next:** [LifeTrac VII](../LifeTrac-VII/README.md)

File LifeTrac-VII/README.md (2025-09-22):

# LifeTrac VII

**Alternative Name:** First Tracked Version / Bulldozer  
**Wiki Reference:** [LifeTrac VII](https://wiki.opensourceecology.org/wiki/LifeTrac_VII) (redirects to [Bulldozer](https://wiki.opensourceecology.org/wiki/Bulldozer))

## Overview

LifeTrac VII represents a major departure from previous wheeled designs as the first tracked version built in the LifeTrac series. This version continued the Tractor Construction Set philosophy but adapted it for tracked bulldozer development, marking the beginning of specialized earth-moving capabilities within the LifeTrac ecosystem.

## Key Features

- **Track System:** First tracked version in the LifeTrac series
- **Construction:** Continued Tractor Construction Set with 4"x4" square tubing
- **Purpose:** Specialized for earth-moving and bulldozer applications
- **Design Philosophy:** Integration of tracked mobility with modular construction

## Design Evolution

### Tracked Mobility
- Excellent ground hold and mobility through rough terrain
- Wide tracks distribute weight over large area
- Prevents sinking in sandy or muddy ground
- Enhanced traction for heavy-duty applications

### Earth-Moving Capabilities
- High-traction, earth-moving functionality
- Suitable for building ponds, berms, and other earthworks
- Road building and land clearing applications
- Integration with bulldozer blade systems

## Technical Specifications

- **Base:** Tractor Construction Set foundation
- **Mobility:** Track-based system for enhanced traction
- **Applications:** Earth-moving, bulldozing, heavy traction work
- **Design:** Lower torque variant with additional weight for stability

## Product Ecology

LifeTrac VII integrates with other GVCS components:
- **Steel:** Produced with Induction Furnace
- **Parts:** Fabricated with CNC Torch Table  
- **Assembly:** Constructed with Welder
- **Base:** Built on Tractor platform

## Historical Significance

LifeTrac VII marked the expansion of the LifeTrac concept beyond traditional tractor applications into specialized earth-moving equipment. This diversification demonstrated the flexibility of the modular construction approach.

## External Links

- [OSE Wiki Page](https://wiki.opensourceecology.org/wiki/LifeTrac_VII)
- [Bulldozer Specification](https://wiki.opensourceecology.org/wiki/Bulldozer_Specification)

## Navigation

- **Previous:** [LifeTrac VI](../LifeTrac-VI/README.md)
- **Next:** [LifeTrac v16](../LifeTrac-v16/README.md)

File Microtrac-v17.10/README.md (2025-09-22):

# Microtrac v17.10

**Alternative Name:** LifeTrac IX  
**Status:** In use in 2021 but modified to shorter tracks  
**Wiki Reference:** [MicroTrac v17.10](https://wiki.opensourceecology.org/wiki/MicroTrac_v17.10)

## Overview

Microtrac v17.10 (also referred to as LifeTrac IX) represents a compact, modular tracked tractor design optimized for versatility and modularity. This version was in active use as of 2021 but was modified to use shorter tracks for improved maneuverability. The design emphasizes the principles of Distributive Enterprise and lifetime design philosophy.

## Key Specifications

### Power System
- **Power Cube:** 16-27 hp as needed (variable configuration)
- **Modularity:** Uses Power Cube system for flexible power management

### Track System
- **Tracks:** 1/2" x 2" steel bar welded track construction
- **Modification:** Modified to shorter tracks (as of 2021 usage)
- **Design:** Robust track system for enhanced traction

### Construction
- **Frame:** 1/4" x 4" perforated steel tubing
- **Shafts:** 3" shafts for wheels and loader arm
- **Philosophy:** Open source design for Distributive Enterprise

### Functionality
- **Productivity:** Full capacity for quick tool attachment
- **Hydraulics:** Hydraulic takeoff to implements on the loader
- **Flexibility:** Multi-function capability through modular attachments

## Technical Features

### Licensing
- **Compliance:** OSHWA and OSI compliant
- **Licenses:** CC-BY-SA-4.0 International, GPLv3, DIN SPEC 3105
- **Philosophy:** Lifetime design approach

### Development Status
- **Stage:** Prototype 2 (Near product release)
- **Dependency:** Pending Universal Track Unit completion
- **Documentation:** See Tractor Construction Set 2017 for design details

## Design Philosophy

Microtrac v17.10 embodies several key principles:
- **Open Source:** Fully open design for global replication
- **Modular:** Component-based design for flexibility
- **Distributive Enterprise:** Designed for distributed manufacturing
- **Lifetime Design:** Built for long-term serviceability and upgradeability

## Related Projects

- **Universal Track Unit:** Key dependency for product completion
- **Tractor Construction Set 2017:** Detailed design documentation
- **Power Cube System:** Modular power system integration

## Historical Significance

This version demonstrates the evolution towards compact, highly modular designs that maintain full functionality while being more accessible for smaller operations and distributed manufacturing.

## External Links

- [OSE Wiki Page](https://wiki.opensourceecology.org/wiki/MicroTrac_v17.10)
- [Tractor Construction Set 2017](https://wiki.opensourceecology.org/wiki/Tractor_Construction_Set_2017)
- [LifeTrac Genealogy](https://wiki.opensourceecology.org/wiki/Lifetrac_Genealogy)

## Navigation

- **Previous:** [LifeTrac v16](../LifeTrac-v16/README.md)
- **Next:** [LifeTrac v17.10](../LifeTrac-v17.10/README.md)

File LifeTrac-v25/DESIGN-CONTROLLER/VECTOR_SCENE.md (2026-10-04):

# LifeTrac v25: Vector Scene mode (VS1) design

> **Status (2026-09-23): design proposal, not implemented.** Rebased on `origin/main` at `d3751286` (2026-09-15), the tree that carries the Murata L072 radio, the strict image path and the FHSS bench campaign. The decisions D-VS1 to D-VS9 (D-VS3 and D-VS3a withdrawn) are proposed and need OSE sign-off; they are listed in [DECISIONS.md](DECISIONS.md#vector-scene-mode--proposed-pending-ose-sign-off). The Vector Lab page ([§8](#8-vector-lab-base-website-live-canvas-input)) needs no radio and can be built first.
>
> **Document roles.** This document is the source of truth for *what to build*. The research and review record, which covers *why*, is [../AI NOTES/2026-09-22_Vector_Scene_Research_ClaudeOpus5_5_v1_0.md](../AI%20NOTES/2026-09-22_Vector_Scene_Research_ClaudeOpus5_5_v1_0.md). It holds the prior-art survey with sources, the current-stack code findings, the FHSS campaign summary, the three competing proposals and how they were scored, and the adversarial-review record.
>
> **Relationship to the shipped pipeline.** VS1 is a new per-frame **codec** inside the existing `TileDeltaFrame` (`codec = 6`) and a new **encode mode** (`EncodeMode.VECTOR = 9`), selected exactly like `mono_g4` is today. It rides the strict image path unchanged: `camera_service.py` → MQTT `cmd/image_frame` → `image_tx_daemon.py` → L072 → air → base L072 → `image_rx_daemon.py` → MQTT `video/tile_delta` → `web_ui.py` → `/ws/state`. Nothing in the L072 firmware changes for the codec itself (Phases 1–3); the optional rung switch of D-VS8 (§4.6) is the one part of this proposal that needs L072 work, and the H7 changes only for the optional S1/S3 pose sources (§5.3). The April plan in [IMAGE_PIPELINE.md](IMAGE_PIPELINE.md) (topic `0x29`, wireframe bitmap, 25 ms fragment cap) is superseded by the shipped path; see [§1](#1-summary-and-design-principles).

---

## 0. Overview

### 0.1 The problem

The image link's bottom rung today is `mono_g4`: a 1-bit Floyd–Steinberg dither per 32×32 tile, zlib-packed (`firmware/tractor_x8/camera_service.py:617-641`). It is honest and cheap, but it is still a **tile** codec:

- A tile costs at least 14 B, and 130 B when dither noise defeats zlib (`camera_service.py:617-641`, `base_station/image_pipeline/codec_decode.py:56-84`). A 243 B frame therefore carries at most 16 of the 96 tiles (225 B after header and bitmap), and a single tile when dither noise defeats zlib, so the operator sees the picture arrive as a rotation of patches over several frames.
- Every frame is a train of tile blobs; a whole-canvas refresh is a keyframe train, and the self-heal keyframe requests chasing lost tiles are what broke the FHSS follower on the bench (222 base `REQ_KEYFRAME` sends, 62.8 % loss, `bench-evidence/RS_12_12_fhss_validation_2026-09-12/RESULTS.md:109-135`).

VS1 sends the **whole frame as geometry** in **one fragment**: horizon, sky and ground gradients, large regions as polygons in their measured colours, trees as ellipses, and edge lines. Shapes keep persistent IDs, so a static scene costs almost nothing and a pan costs one group-shift record. There are no keyframe trains, no keyframe requests and no tiles to lose. It is the mode the system drops to when the signal is degraded and the tile modes are failing, so it carries its own degradation ladder (§4.5): shorter frames, more repeats and less detail as loss rises, with no acknowledgement traffic.

### 0.2 What the operator sees

When VECTOR is the active encode mode, the console camera panel shows a stylised live picture instead of photographic tiles:

- **Sky and ground** as two smooth gradients in the measured colours, split by the real horizon, with a tree-line profile along it.
- **Large regions** as polygons filled with their measured mean colour and a simple gradient: the near field, the track, a shed wall.
- **Isolated trees and shrubs** as coloured ellipses.
- **Edge lines** for ruts, fences, structures and overhead wires.
- **Hatched "unknown" areas** (HOLE records): holes the tractor has reported inside a region but not yet described.
- **Dashed "UNCLASSIFIED" boxes** for anything unusual in the tractor's path, drawn above all scene layers and the self-model.
- **The tractor's own hood**, drawn in outline at the base (from the OpenSCAD model once the camera is calibrated; as the hand-drawn mask outline before that). The hood is normally masked and not transmitted. The loader arm is drawn too if an arm sensor is fitted.
- **Honesty cues:** a banner that raw mode cannot hide ("VECTOR — NOT CAMERA PIXELS · age · loss"), per-shape age styling, and a "SAFETY DETECTOR: NO PIXELS" chip.

The whole worked example scene of §3.6 (23 records, 129 B) fits in **one frame** at either radio profile. Later frames add polygon vertices, holes and fine detail while the scene is static, and a 21-bit group shift moves every shape when the tractor pans.

| Radio profile | VS body per frame | Records per frame (est.) | Worked scene |
|---|---|---|---|
| p1 FHSS (BW250) | 197 B | 1,563 bits ≈ 21–35 records | 1 frame, 545 bits spare |
| p2 DTS (BW500) | 237 B | 1,883 bits ≈ 25–43 records | 1 frame, 865 bits spare |

### 0.3 How it flows

```mermaid
flowchart LR
  CAM["Camera 384x256, 2 fps"] --> EXT["camera_service: extract layers<br/>M, L0-L4 at 96x64 / 192x128"]
  EXT --> TMP["match to live shapes<br/>(T: keep IDs, shift, confirm)"]
  TMP --> PACK["rank by value per bit,<br/>pack ONE fragment (P)"]
  PACK -->|"MQTT cmd/image_frame"| TXD["image_tx_daemon<br/>pacing, single fragment"]
  TXD -->|"L072, FHSS slot or DTS"| RXD["image_rx_daemon<br/>reassemble, republish"]
  RXD -->|"MQTT video/tile_delta"| STORE["web_ui: VectorSceneStore<br/>epochs, ages, badges"]
  SM["self-model<br/>CAD + calibration + pose"] --> PUB
  STORE --> PUB["StatePublisher<br/>/ws/state snapshot"]
  PUB --> BR["browser: vector_renderer.js<br/>+ self_model_overlay.js"]
  LAB["Vector Lab worker<br/>same codec, live canvas input"] -.->|"lab/* topics only"| LABUI["/vector_lab page"]
```

Paint order, from bottom to top:

```
 11  banner "VECTOR — NOT CAMERA PIXELS"          (inside the vector canvas; raw mode cannot hide it)
 10  staleness styling + badges
  9  detections
  8  corridor anomalies (dashed, "UNCLASSIFIED")  (always above the self-model)
  7  self-model (hood outline; sensed arm)        (never opaque over transmitted pixels)
  6  L3 edges (ruts, fences, structures, overhead lines)
  5  L4 detail
  4  L2 trees / shrubs (ellipses)
  3  HOLE hatches
  2  L1 masses (polygons + gradient)
  1  L0 sky / ground gradients + skyline      <- first to arrive
```

### 0.4 How the original ideas map to the design

| Idea | Where it lives in this design |
|---|---|
| Convert everything in the frame to polygons | L1 masses. POLY records with 3–10 vertices; detail is added by INSERT records (§2.5, §3.3). |
| A simple colour gradient matching the average colour | FILL uses the measured mean colour (RGB444, or a palette slot only when within ΔE ≤ 4) plus an optional least-squares linear gradient (§3.3). Colours are never invented (principle 4). |
| Sky and ground as the first layer | L0 HZN record: 42–58 bits, the first record of every new epoch. Later frames send a 15-bit residual (§2.4). |
| More detail as bandwidth allows | Records are ranked by error reduction per bit (CELF), so a frame cut short still holds the best picture for its bytes (§2.9). While the scene is static, spare bits add vertices and detail (§4.3). |
| Trees and shrubs as basic shapes with varying detail | L2 TREE/SHRUB ellipses of 34–51 bits. A merged tree line becomes SKYLINE. Trunks are drawn only when the lens is zoomed in enough to resolve them (§2.6). |
| A 3D model of the tractor's own parts at the base | §5. The OpenSCAD model is exported to a visualisation-only model, then calibrated. The hood is masked on the tractor and costs 0 bits. The arm is posed from a sensor (S1). Vision and valve estimates are Lab-only and clearly labelled. The bucket is never masked. |
| Don't re-send the same vectors | Persistent shape IDs with UPD, UCOL, DEL and CONFIRM records. GSHIFT and GZOOM move whole groups. IMU horizon prediction happens at the base (§4). |
| Other optimizations | §9. |
| Testable on the base station website | Vector Lab (§8): the live canvas at both profile budgets side by side, with per-layer bit bars, loss simulation, a hex frame scrubber and golden-fixture export. |

### 0.5 Reading guide

| If you are… | Read |
|---|---|
| Deciding whether to adopt this | §0, §1 (budget), §4.5 (degraded-signal operation), §6 (mode and policy), §10 (blockers), §11 (decisions and roadmap) |
| Building the Vector Lab (Phase 1) | §2, §3, §7.2, §7.5, §8 |
| Integrating on the strict path (Phase 2) | §3.1, §6, §7 |
| Working on the self-model (Phase 3) | §5, and CALIBRATION.md §6 once it is written |
| Implementing the modem-rung switch on the L072 and the daemons (D-VS8) | §4.5.6, §4.6, §7.4 |

---

## Conventions

**Path key.** `DC/` = `LifeTrac-v25/DESIGN-CONTROLLER/`, `bs/` = `DC/base_station/`, `x8/` = `DC/firmware/tractor_x8/`, `DS/` = `LifeTrac-v25/DESIGN-STRUCTURAL/`, `BE/` = `DC/bench-evidence/`.

- **Estimates.** Anything marked *(est.)* has not been measured.
- **Computed figures.** Airtimes come from read-only runs of `bs/lora_proto.py` (`lora_time_on_air_ms`, `max_image_fragment_body`) at `PHY_IMAGE_BW250` (p1 FHSS) and `PHY_IMAGE_BW500` (p2 DTS), SF7/CR4-5/preamble 8 (`bs/lora_proto.py:150-151`), including the 8 B hop header and the 4 B fragment header. Bit packing and footprint figures come from stdlib Python.
- **Review status.** The first draft (2026-09-22) was written against a checkout from 2026-05-01 and reviewed adversarially against that stack (3 blockers, 34 major, 23 minor issues, all resolved). It was then rebased on the 2026-09-15 tree, which replaced the budget, transport, mode and integration sections. The layer model, record set, temporal rules, self-model and Lab carried over. The per-issue dispositions are in the appendix of the [research note](../AI%20NOTES/2026-09-22_Vector_Scene_Research_ClaudeOpus5_5_v1_0.md#appendix-b-adversarial-review-dispositions).

---

## 1. Summary and design principles

### What changes

A new per-frame codec and encode mode on the shipped strict image path:

| Layer | Content |
|---|---|
| L0 | Horizon, with sky and ground as vertical gradients in the measured mean colours, plus a skyline/treeline profile |
| L1 | Large regions as polygons, each with its measured mean colour and an optional linear gradient. Holes are declared, never silently painted over. |
| L2 | Isolated trees and shrubs as ellipses |
| L3 | Edge polylines, including overhead lines. The "edges only" view is L3 with fills toggled off. |
| L4 | Residual detail |

- Every shape has a persistent ID, and **every frame is one fragment that decodes on its own**.
- The tractor never spends bits on its hood, and optionally on its arm members. The base draws them from a CAD self-model at a pose whose source is always labelled.
- The bucket and cutting edge are **never masked** (§5).
- The `0x29 video/wireframe` topic, the 12,293 B edge bitmap in `x8/x8_image_pipeline/encode_wireframe.py` and `bs/image_pipeline/wireframe_render.py` are dead code on the strict path (no importers outside `bs/tests/test_image_pipeline.py`); VS1 replaces the idea, not the code path.

### Budget (computed)

The strict path sends image fragments in plaintext: an 8 B hop-sync header, a 4 B fragment header (`0xFE | frag_seq | frag_idx | total−1`, `bs/lora_proto.py:819-876`), and up to 243 B of payload (the 247 B `TX_FRAME_BODY_MAX` includes the fragment header, `bs/lora_proto.py:835-836`; the 170 ms cap trims it to 203 B at BW250). There is no KISS and no AES-GCM on this path (`x8/image_tx_daemon.py:36-42`, `bs/image_rx_daemon.py:12-14`). The per-fragment airtime cap is 170 ms (`LIFETRAC_FRAG_AIR_CAP_MS`, `bs/lora_proto.py:837`); the April 25 ms cap was dropped for image traffic (TODO.md RS-9.7).

| Profile | Fragment body | On air | Airtime | VS body (body − 6 B `TileDeltaFrame` header) | Record bits (body × 8 − 13) |
|---|---|---|---|---|---|
| p1 `FCC_15_247_FHSS_50CH_BW250` | 203 B | 215 B | 169.1 ms, one per 200 ms slot | **197 B** | **1,563** |
| p2 `FCC_15_247_DTS_BW500` | 243 B | 255 B | 99.9 ms | **237 B** | **1,883** |

Sources: `x8/image_tx_daemon.py:308` (`_FRAG_BODY_BY_PROFILE`), `SETTINGS_REFERENCE.md` §2.1, `CONTROL_PLANE_DESIGN.md:101`.

- The `TileDeltaFrame` byte budget covers the whole wire payload including its header (`x8/camera_service.py:1066-1075`), and the live budget arrives on the retained `tractor/link_budget` topic as one fragment (`x8/image_tx_daemon.py:435, 1054-1088` → `x8/camera_service.py:824-841`). VS1 sizes every frame to that budget.
- Airtime is paced by time-on-air (`x8/image_tx_daemon.py:355-411`, 0.92 headroom), so a short frame really is cheaper: a 12 B VS body costs 18.0 ms at DTS (36.0 ms at FHSS), a full frame 99.9 ms (169.1 ms). Airtime moves in 3.5 B / 1.28 ms steps at BW500 (2.56 ms at BW250), so bodies of 12–15 B all cost the same (18.0 ms at DTS, 36.0 ms at FHSS).
- At the default 2 fps (`x8/camera_service.py:109`) a full VS frame uses 20 % of DTS airtime and 34 % of FHSS airtime (2 of every 5 slots). A static scene converges to CONFIRM/DIGEST-only frames of a few bytes.

**What this replaces.** The first draft of this document (written against the 2026-05-01 checkout) budgeted 10 B per LoRa frame under a 25 ms cap with 28 B of GCM and KISS framing per frame. None of that exists on the strict path. The measured link gives 699–812 B/s on FHSS and 1.75–2.0 KB/s on DTS (`TODO.md:202-210`; `BE/FW_BATCH1_acceptance_2026-07-30/RESULTS.md:86`; `TODO.md:458-461`, tractor-side), so a VS frame is a single fragment with room to spare, and the design's value moves from "fit in 10 bytes" to **"one fragment per frame, no keyframe trains, honest at the floor"**.

### Principles

1. **Frame-atomic and idempotent.**
   - One fragment per frame; no multi-fragment trains, so no penultimate-fragment loss and nothing to reassemble.
   - Defines are absolute. UPD, GSHIFT, GZOOM and GAIN are *cumulative since epoch start* rather than chained deltas. INSERT is addressed against the immutable define, not the current vertex list.
   - The base applies each **field** (geometry, offset, colour) last-writer-wins by capture time.
   - Loss removes or ages content and never corrupts geometry. Design target: at least 12 % frame loss (the FHSS legs measured 2.1 % with a quiet command plane, `BE/RS_12_12_fhss_validation_2026-09-12/RESULTS.md:90-100`, and 10.5–20.9 % under the keyframe-storm camera load, `BE/RS_12_15_clock_authority_2026-09-14/RESULTS.md:300-352`).
2. **Every record describes the current capture.** The tractor re-measures before it re-sends anything: repeat-once and the carousel re-verify each shape against the newest capture (§4). A frame's age nibble is therefore true for every record in it, as C6 requires (`DC/IMAGE_PIPELINE.md:33`).
3. **Embedded order.**
   - Records are ranked by weighted ΔD per bit (CELF lazy greedy, §2) against a mirror of the base display.
   - Weights: 0 on the self-mask; ×3 in the path corridor and for overhead-line candidates; ×0.5 in the rest of the sky.
   - A frame cut short by the budget still leaves the best picture for its bytes.
4. **Measure, don't invent, and disclose omissions.**
   - Every colour is a measured mean. A palette slot is used only when it is within ΔE76 ≤ 4 of that mean.
   - Every shape comes from real pixels. Extrapolated content is PREDICTED (4); CAD content is MODEL (8).
   - The scene is a lossy *summary*. Objects can be missing, so the UI publishes the minimum-object-size table (§2.3), the "N detected / M shown" count, and hatched HOLE and NOT-TRANSMITTED regions.
5. **The base decides and the browser draws** (C5, `DC/IMAGE_PIPELINE.md:32`).
   - One pure-stdlib codec is shared by the tractor, the base store and the Lab (`bs/image_pipeline/vector_scene/`, deployed to the tractor next to `lora_proto` by the harness push list).
   - The browser receives only JSON.
6. **Supervisory tier; no safety claim.**
   - VECTOR is a "look, then move" view. **v25 has no working person detector.** Both `x8/x8_image_pipeline/detect_nanodet.py` backends return `[]`, and no tractor code emits `CMD_PERSON_APPEARED`. The base R6 detector gets no fresh pixels in VECTOR.
   - The console therefore shows "SAFETY DETECTOR: NO PIXELS". The speed cap (§6) applies once the hydraulic drive plane is on air; today no ControlFrame has flown and the E-stop is the 200 ms deadman ("stop by absence").
7. **No keyframe trains.** An epoch start is one frame (an absolute HZN — ABS, or NO_HORIZON — plus LAYER_CLEAR). Repair is level-triggered inside the next scheduled frame, never by a request that grows the load it responds to. This is the same conclusion the bench reached for tiles: the self-heal keyframe request was net harmful and was replaced by the `0x6C` stale-tile report (`TODO.md:136-140`).
8. **Same radio profile as everything else.** Image frames and base commands share whichever profile is active; there is no per-frame PHY split. On FHSS a VS frame occupies one 200 ms slot and base commands steal slots; on DTS commands ride the ~17 ms pacing gaps (`CONTROL_PLANE_DESIGN.md:96-120`, `TODO.md:141-159`).
9. **Degrade by shrinking, repeating and simplifying, never by asking.** Under measured loss the encoder sends shorter frames, repeats the important records more often and drops detail (§4.5). It never adds acknowledgement or retry traffic, because the bench showed that such traffic amplifies loss on this half-duplex link.

---

## 2. Layer model and tractor pipeline

### 2.1 Pre-stage (once per camera frame; 2 fps by default, `x8/camera_service.py:109`)

1. **Frame.** Take the newest 384×256 RGB frame. In VECTOR mode, lock auto-exposure and auto-white-balance where the V4L2 driver allows (B9).
2. **Resize and colour spaces.** `cv2.resize(INTER_AREA)` to 192×128 and 96×64. Convert to Lab for k-means and YCoCg for gradients.
3. **Global gain.** Estimate a per-channel log-gain against the epoch reference, from trimmed means of stable L1 masses. Normalise the frame by it before k-means, and send it as a GAIN record if it changes by more than 2 %. A cloud or auto-exposure step then costs one 25-bit record instead of a UCOL for every shape.
4. **Ego-motion.**
   - **Far and all groups:** `register.py` phase correlation at 96×64 (`x8/x8_image_pipeline/register.py:43-74`), after the B7 fixes.
   - **Ground group:** sparse Lucas–Kanade (`cv2.calcOpticalFlowPyrLK` on 30–50 Shi–Tomasi corners below the horizon at 192×128, 2–4 ms est.), fitted to the one-parameter ground-plane model of §4.4 to give the GZOOM parameter u. When LK has fewer than 12 inliers, use GPS speed.
   - **"moving"** means shift ≥ 1 px in 384-px units, or |u| above threshold, or any valve active.
5. **Weight map W.**
   - Self-mask = 0.
   - Path corridor ×3: a fixed trapezoid before calibration, a projected machine-width strip after.
   - Sky ×0.5, except ×3 for L3 overhead-line candidates, and ×1 inside the loader's swept volume while the sensed arm is above horizontal.
6. **Undistortion.** Once calibration exists, undistort only the sampled points (horizon samples, contour vertices, feature points) with `cv2.undistortPoints`, never the whole frame.

### 2.2 Layers

The target is an A53 at 1.8 GHz, numpy + OpenCV, single core. All times are est.

**Gate:** end-to-end M→P, including T, P and L4, p95 ≤ 100 ms on the **tractor** X8 using host Python, measured by `DC/tools/vector_bench.py` with the detector and register workloads running concurrently and a 30-minute thermal soak (§8.6).

| Layer | Content | Tractor extraction | Res. | ms (est.) | IDs |
|---|---|---|---|---|---|
| **M** self-mask | Static hood/frame. Dynamic **arm members only**, under the §5.3 conditions. **Never the bucket or cutting-edge zone.** | Hand-drawn bounded polygon (MVP) or projected CAD hull, `cv2.fillPoly`. Static mask eroded 1 cell, dynamic 2 cells. Structural anomaly test (§5.2). | 96×64 | 1–2 | — |
| **L0** frame | Horizon (straight, or quadratic before calibration), sky and ground gradients, skyline profile | §2.4 | 96×64 | 2–5 | singleton |
| **L1** masses | Fields, track, buildings, water, holes, corridor anomalies | §2.5 | 96×64 (corridor at 192×128) | 12–30 | 1–31 masses; 80–87 anomalies |
| **L2** plants | Isolated trees and shrubs | §2.6 | 96×64 | 2–4 | 32–55 |
| **L3** edges | Ruts, fences, structures, overhead lines, contact edges | §2.7, computed on the **unmasked** image; edges inside masks are dropped at pack time but kept for S2 | 192×128 | 5–12 | 56–79 |
| **L4** detail | MVP: the tail of the L1/L2 candidates. Phase 4: closed-form fits (§2.8). | shared | 96×64 | 0–3 | 88–127 |
| **T** temporal | Predict each live shape with GSHIFT and GZOOM, then match: regions by IoU on label maps, edges by chamfer distance. Choose UPD / UCOL / redefine / DEL / CONFIRM, whichever is cheapest. Maintain the mirror. | §4 | 96×64 | 5–12 | — |
| **P** pack | CELF lazy greedy, ΔD per bit on a 48×32 flat-fill mirror, ≤ 64 candidates, packed into one F-byte frame | §2.9 | 48×32 | 5–15 | — |

**Total M→P ≈ 32–83 ms per frame (est., sum of the rows above)**, which at the 2 fps camera default is 6–17 % of one core. The §2.1 pre-stage (resize, colour conversion, LK 2–4 ms) comes on top.

- WebP tile encoding (`x8/camera_service.py:644-700`) is skipped in VECTOR mode, so net tractor CPU falls from the roughly 140 % of one core in `DC/IMAGE_PIPELINE.md:60`.

**Paint order, bottom to top:**

1. L0 sky, ground and skyline
2. L1 masses (area-descending, VTracer-style stacking)
3. HOLE hatches
4. L2
5. L4
6. L3
7. self-model
8. **corridor anomalies** (IDs 80–87; dashed, high-contrast, "UNCLASSIFIED")
9. `0x26` detections
10. staleness styling and badges
11. banner

Corridor anomalies sit above the self-model, so the model can never hide one.

**Reprojection groups cost 0 bits.** The base assigns them geometrically:

- **far:** L0, the skyline, and shapes wholly above the horizon;
- **ground:** everything else.

### 2.3 Minimum detectable object (published in the doc and shown in the UI)

Pinhole model, fx = 192/tan(hfov/2): 89.5 px at 130°, 542 px at 39° (computed).

Outside the corridor, components under 6 cells at 96×64 are dropped. Inside the corridor the floor is 2 cells at 192×128.

| Zoom | Distance | Person (0.5 × 1.7 m), px / 4-px cells | Smallest square object, outside corridor | Smallest square object, inside corridor |
|---|---|---|---|---|
| 130° | 5 m | 9.0 × 30.4 px / 17 cells | 0.55 m | 0.16 m |
| 130° | 10 m | 4.5 × 15.2 px / 4.3 cells (**below 6: dropped outside the corridor**) | 1.09 m | 0.32 m |
| 130° | 20 m | 2.2 × 7.6 px / 1.1 cells | 2.19 m | 0.63 m |
| 39° | 10 m | 27 × 92 px / 156 cells | 0.18 m | 0.05 m |
| 39° | 20 m | 14 × 46 px / 39 cells | 0.36 m | 0.10 m |

The console shows this row for the current zoom, for example "objects < 1.1 m at 10 m may not appear outside the corridor". This assumes contrast with the surroundings; brown on soil can vanish at any size.

### 2.4 L0 algorithm (revised)

1. **Per-column score (24 columns), ordered on chroma and texture, not luma.**
   - Sky evidence: high (B−R), or bright neutral for overcast; low local variance; low Sobel gradient density.
   - Ground evidence: texture and vegetation index.
   - Luma is not used for ordering. Blue sky at Y ≈ 114 is darker than straw (189) or snow (241) (computed).
2. **Exclude loader columns.** Skip columns inside the loader's pose-independent swept envelope: the CAD envelope over the joint limits once calibrated, or a hand-drawn "loader zone" before that. A raised bucket's straight top edge cannot become the horizon.
3. **Fit.**
   - Take the strongest sky→ground transition per remaining column.
   - With calibration: undistort those points (`cv2.undistortPoints`) and fit a line.
   - Before calibration: fit y = a + bx + cx². At 2.8 mm / 130° a straight horizon 10–25° off-axis sags 11.5–27 px between centre and ±60° (computed), so a line fails. The curvature is sent as `curv4` (4 px steps, −32..+28 px at the frame edge, which covers the 27 px case).
   - Two-pass trimmed least squares.
4. **Accept** only if all of these hold:
   - ≥ 40 % of the non-excluded columns lie within 2 cells;
   - sky is above ground on chroma/texture;
   - temporal consistency: |Δ| from the previous horizon plus the IMU delta ≤ 3°, or the jump is seen in 2 consecutive captures.
5. **Otherwise mode = NO_HORIZON.** This is the *expected* state during loader work with the camera tilted down, not a failure. NO_HORIZON sends a top/bottom vertical gradient.
6. **IMU prior (Phase 3).** Roll gives the slope, and pitch × fy gives the offset. The search band is in *angle*, ±3°, which is ±fy·tan 3° = ±4.7 px at 130° and ±28 px at 39° (computed).
7. **Colours and skyline.**
   - Colours are trimmed means of the top band and near-horizon band (sky), and the near-horizon band and bottom band (ground).
   - The skyline is the per-column sky/non-sky transition above the horizon. A merged treeline or hedgerow becomes SKYLINE, not TREE records.

### 2.5 L1 algorithm (revised)

1. **Colour stability.** Assign each pixel to the previous refresh's centres in numpy, then call `cv2.kmeans(K=8, 3 iterations, KMEANS_USE_INITIAL_LABELS)`. `cv2.kmeans` cannot take initial centres directly. Match the new clusters to the old by centre distance, so indices stay stable.
2. **Vegetation feature.** Add ExG−ExR, heavily weighted, computed *after* grey-world or sky-referenced white-balance normalisation. Threshold with Otsu, not a fixed 0. Without normalisation a leaf scores +0.308, and under warm low sun +0.028 or −0.094 (computed).
3. **Components.** 3×3 mode filter, then `connectedComponentsWithStats`. Drop components under 6 cells outside the corridor. Inside the corridor, run at 192×128 with a 2-cell floor.
4. **Contours and holes.** `findContours(RETR_CCOMP)` and `approxPolyDP` at ε = 1 cell.
   - Holes of 2 cells or more are candidates for **HOLE** records, weighted by W.
   - A hole the tractor has not sent yet is painted in the parent colour. This is a disclosed omission (§2.3), not a claim.
   - Inside the corridor, every non-ground component goes through the ANOM path instead (step 7).
5. **Progressive vertices.** Order vertices by Visvalingam–Whyatt area. The define carries the top 3–4 (3–10 allowed). INSERT records add the rest (§3.3). This is the "basic shape first, detail as bandwidth allows" progression.
6. **Gradient.** A least-squares plane Y = a + bx + cy from `np.bincount` moments, on gain-normalised pixels.
7. **Corridor anomaly.**
   - Fit a trimmed 2-component GMM on **shadow-invariant chromaticity** (normalised rg) over the bottom band. Exclude the self-mask and the loader swept envelope.
   - Components inside the corridor with Mahalanobis distance > 3 become ANOM records (IDs 80–87).
   - Regions that stay fixed relative to the tractor while GSHIFT or GZOOM is non-zero (the tractor's own shadow) are suppressed.
   - This is a colour-anomaly *aid*, not a detector (principle 6).

### 2.6 L2 plants (revised)

A **tree candidate** is a vegetation cluster that meets all of these:

- darker, and higher in local variance, than the fitted ground-vegetation model;
- touches or rises above the horizon or skyline;
- solidity ≥ 0.8 and ellipse IoU ≥ 0.8 against `cv2.fitEllipse`.

Other points:

- A merged, non-convex treeline becomes SKYLINE.
- A **shrub** is the same test below the horizon, with area < 60 cells.
- In pasture or growing crop, the whole-ground vegetation component is L1, never L2.
- **Trunks are disabled unless fx > 300 px** (zoomed in). At 130° a 0.4 m trunk at 50 m is 0.72 px (computed).

### 2.7 L3 edges (revised; replaces the wireframe)

1. **Edge map.** Sobel magnitude at 192×128, masked by nothing. Canny thresholds come from the 90th and 97th percentiles of Sobel magnitude, not from median luma. A median-luma rule scales with brightness: bright scenes give 119/239 and lose everything, dark ones give 26/53 and flood with texture. EDPF (ximgproc, parameter-free) is optimisation #14.
2. **Prune early.** `connectedComponentsWithStats` on the edge map. Keep only the top K = 30 components by length × contrast × W *before* any per-contour Python.
3. **Polylines.** `findContours` and `approxPolyDP` at ε = 1.5 px, split into polylines of ≤ 4 segments.
4. **Class** (`cls3`):

   | Value | Class | Rule |
   |---|---|---|
   | 0 | rut | — |
   | 1 | structure | — |
   | 2 | fence | — |
   | 3 | contact | Edge within the bucket zone |
   | 4 | **overhead** | Long, thin, near-straight edge above the horizon; W ×3 |
   | 5–7 | reserved | Reject |

5. **Matching.** Distance-transform the previous refresh's edge raster after ego-motion prediction, and score each new polyline by mean chamfer distance. Keep the ID if the chamfer is ≤ 1 cell; with hysteresis, redefine only above 1.5 cells.

### 2.8 L4 detail (revised)

- **MVP:** the tail of the L1/L2 candidate list.
- **Phase 4:** closed-form fits. Take the highest-residual connected component and fit an ellipse from `cv2.moments`, with the mean colour and plane gradient, in O(pixels). Alternatively, place Marwood-style Delaunay vertices at residual peaks (#18).
- **No Python hill-climbing search.** primitive-gpu needed 21.5 s for 200 triangles on 8 desktop cores. A compiled `geometrize-lib` extension is considered only after an X8 benchmark.

### 2.9 Pack (revised)

- **Candidates:** new defines, UPD / UCOL / redefine, INSERT, HOLE, BLOB, capped at 64 per frame (top by a cheap prior).
- **Initial score:** ΔD is computed once per candidate over its bounding box on a **48×32 flat-fill mirror**.
- **CELF lazy greedy:** pop the heap top. Re-evaluate it only if its box overlaps a shape committed since its last evaluation, then commit it or re-push it.
- **Packing:** into one F-byte frame, in the §4.2 priority order.
- **Cost:** about 64 initial evaluations + ≤ 40 re-evaluations × ~50 µs, about 5–15 ms (est.).

---

## 3. Wire format: `TileDeltaFrame` codec `VECTOR` (VS1)

**Container.** A VS1 frame is a `TileDeltaFrame` whose `codec` byte is `CODEC_VECTOR = 6` (ids 0–5 are assigned and 6–14 are free, `bs/image_pipeline/frame_format.py:79-88`; 5 is `CODEC_WEBP_RAWSTREAM`). The 6 B header is unchanged:

```
u8  frame_kind   ; 1 = epoch start (VS "key"), 0 = update — reuses the tile I/P meaning
u8  seq          ; TileDeltaFrame sequence (image_tx_daemon / image_rx_daemon use it as today)
u8  grid_w, grid_h, tile_px   ; canvas geometry, so the base knows the coordinate frame
u8  codec = 6    ; VECTOR
```

After the header comes the **VS body** instead of the changed-tile bitmap and tile blobs. The parser branch is the only format change on the base (§7.1): `parse_tile_delta_frame` currently rejects trailing bytes and knows no codec 6 (`frame_format.py:136-200`).

Why a codec id rather than a new top-level magic:

- `image_tx_daemon` treats a first byte of `0x01` as a keyframe: never batched, and duplicated when its own TX-failure ratio exceeds 0.5 % (`x8/image_tx_daemon.py:763, 1103-1118`). VS epoch starts inherit that handling; the encoder adds its own repeat-once (§3.1).
- `image_rx_daemon` reassembles, re-encodes and republishes `TileDeltaFrame`s (`bs/image_rx_daemon.py:543-557`) and the web UI already routes `video/tile_delta` (`bs/web_ui.py:1109-1113, 1417`); a codec branch reuses all of it.
- The first byte can never collide with the fragment magics `0xFB`–`0xFE` or the batch magic `0xB5` (`frame_format.py:37`).

### 3.1 Frame on air

`hop header 8 B | fragment header 4 B | TileDeltaFrame header 6 B | VS body (F bytes)`, with **F ≤ 197 (FHSS) or 237 (DTS)**, so that the fragment body stays within the profile's 203 / 243 B (`x8/image_tx_daemon.py:308`).

| VS body | On air | p1 FHSS BW250 | p2 DTS BW500 |
|---|---|---|---|
| 12 B (CONFIRM + DIGEST, static scene) | 30 B | 36.0 ms | 18.0 ms |
| 40 B | 58 B | 56.4 ms | 28.2 ms |
| 129 B (worked scene, §3.6) | 147 B | 120.4 ms | 60.2 ms |
| 197 B (full FHSS frame) | 215 B | 169.1 ms | 84.5 ms |
| 237 B (full DTS frame) | 255 B | — (over the 170 ms cap) | 99.9 ms |

- **Always one fragment.** The encoder sizes to the live `tractor/link_budget` (§1) and never emits a body over F. There are no trains, so the short-final-fragment "ride" loss found in RS-12 (`BE/RS_12_bulk_floor_2026-08-16/RESULTS.md:182-199`) cannot occur.
- **Epoch start = `frame_kind` 1.** `image_tx_daemon` adds a second copy only when its cumulative local TX-failure ratio exceeds 0.5 % (`x8/image_tx_daemon.py:1103-1118`); air loss is invisible to it, so VS1 does its own repeat-once: the next frame carries the absolute HZN + LAYER_CLEAR again (70 bits, or 52 with a NO_HORIZON anchor, §3.5) — a repeat the store treats as idempotent (§3.3), so it cannot erase what the first frame defined. When the daemon's copy does fire it uses the 5 B `0xFD` header, whose chunk is 1 B smaller than v1's (`pack_image_fragments_v2`, `bs/lora_proto.py:884`; until #132, merged 2026-09-24, the packer re-wrapped v1-sized chunks, so a full-F copy was 248 B at DTS and refused by the L072, or 171.6 ms at FHSS). VS1 therefore caps epoch-start frames at F − 1 (196 / 236 B) so that a copied epoch start stays one fragment instead of spilling a 1-byte runt into a second pair. The same arithmetic applies to today's full-budget tile keyframes.
- **No crypto.** P3 image traffic is plaintext today; the planned D14 split-trust envelope (4 B seq + 2 B CRC32, `LORA_PROTOCOL.md` priority-class table) would cost 6 B of body when it is switched on. VS1 reserves nothing for it; F simply shrinks by 6.

### 3.2 VS header: 13 bits, explicit in every frame

```
byte0: bit7   0      marker (kept for a future top-level-magic transport; harmless here)
       bit6   V      version (0 = VS1; 1 = reserved -> reject whole frame, count vs_bad_version)
       bit5   K      key: 1 = this is the epoch-start frame (mirrors frame_kind)
       bit4-1 AAAA   capture age, 200 ms units; 15 = saturated (>= 3.0 s, rendered stale)
       bit0   E3  ┐
byte1: bit7-5 E2-0┘  EEEE epoch mod 16
byte1: bit4-3 LL     degradation level the encoder is running: 0 = V0 … 3 = V3 (§4.5.4)
byte1 bit2 ..       records, MSB-first bitstream; records never cross frames
```

- **Age.** `camera_service` writes its encode latency into AAAA at pack time, and `image_tx_daemon` adds the frame's queue residence at dequeue (codec 6 only: payload byte 6, bits 4–1, in the plaintext VS header, patched just before `_pack_for`, `x8/image_tx_daemon.py:1108-1118`; the daemon already knows the enqueue time, `:559-574`), rounding up and saturating at 15. AAAA is therefore encode + queue wait, and the base computes capture time = rx_ms − airtime(profile, length) − 200·AAAA, which is within one 200 ms unit of the truth either way (the ceiling rounds ages older; the unreported slot wait, ≤ 200 ms, rounds them younger). Without the daemon's patch, `rx_ms − 200·AAAA` would be too young by the whole queue wait (up to the 1.5 s below) plus airtime. VECTOR mode sets `LIFETRAC_FRAME_MAX_AGE_MS=1500`, and for codec-6 frames the daemon drops an over-age frame **unconditionally** at dequeue, not only when a fresher one is queued (`x8/image_tx_daemon.py:1136-1145` drops conditionally today; default 10 s): a lone late frame is worth less than nothing, because it would win LWW with an understated age. AAAA therefore never reaches 15 on a working link (1.5 s plus encode is about 9 units); if it does, the store treats it as a bound — the frame's records fill absent state but never supersede state with a known capture time.
- **K and `frame_kind` must agree**; the parser rejects a mismatch.
- **LL** is the level the *encoder* is at, whether the base commanded it or the tractor self-selected it (§4.5.4). Frame size cannot carry this: a quiet V0 frame is smaller than a V2 frame.

**Record bits per frame = F × 8 − 13**

| Profile | F | Record bits |
|---|---|---|
| p1 FHSS | 197 | **1,563** |
| p2 DTS | 237 | **1,883** |

### 3.3 Records: canonical prefix code (Kraft sum exactly 1)

**Field conventions.** Bits are MSB-first (§3.2). Every signed fixed-width field (`dx4`/`dy4`, `dx8`/`dy7`, `ang6`, `curv4`, `dy5`, `dang4`, `dl3`, `dl4`) is two's complement. Count fields are offset: `n3` = vertices − 3, `k2` = segments − 1, `cnt4` = count − 1, and every `(v+1)·unit` field is the code plus one. `grid1` selects the define's grid: 0 = 8 px (48 × 32 cells, `v0` 11 bits), 1 = 4 px (96 × 64 cells, `v0` 13 bits). A record's layer is its id range (§2.2, §3.4): masses 1–31, plants 32–55, edges 56–79, corridor 80–87, L4 88–127; within L2, L3 and L4 shapes are painted in ascending id order (L1 is area-descending, §2.2). A POLY ring is closed (the last vertex joins `v0`) and filled with the non-zero winding rule; INSERT and HOLE apply to POLY only (EDGE polylines are re-sent whole).

| Prefix | Record | Fields (bits) | Size |
|---|---|---|---|
| `00` | **UPD** | id7 (≠ 0), dx4, dy4: 4 px units, signed −8..+7, so **−32..+28 px**, cumulative offset from the define anchor | 17 |
| `010` | **POLY** define | id7, grid1, n3 (3..10 vertices), v0, (n−1) × EG2 zigzag (dx, dy) in grid cells, FILL | Gradient triangle 69; flat RGB triangle 63; palette triangle 55; flat quad about 75 (est.) |
| `011` | **TREE / SHRUB** | id7, centre 11 (8 px grid, x6 y5), rx3, ry3 ((v+1)·4 px, axis-aligned ellipse), FILL, trunk1 (1 ⇒ an `h3` field follows: a 4 px wide vertical bar of height (h3+1)·8 px below the ellipse, painted in palette slot 6; the encoder sets it only with a narrow lens, fx > 300 px, §2.6) | 34–48 by FILL (42 with a flat RGB fill); +3 with a trunk |
| `100` | **EDGE** | id7, cls3 (§2.7 table; 5–7 reject), v0 13 (4 px grid), k2 (segments − 1, so 1..4), k × EG2 (dx, dy) each from the previous vertex; an open polyline | 1 segment 40; 3 segments 64 (est.) |
| `1010` | **HZN** | mode2; see the HZN modes below | 15–57 |
| `1011` | **DEL** | id7 | 11 |
| `1100` | **UCOL** | id7, FILL | 17–31 |
| `1101` | **GSHIFT** | grp2 (0 far, 1 ground, 2 all, 3 L4), dx8, dy7: 2 px, **cumulative since epoch start**, −256..+254 / −128..+126 px. Membership is fixed at define time: L4 ids are group 3; every other shape is *ground* if its `v0` lies below the epoch's horizon line, else *far* (in a NO_HORIZON epoch nothing is above a horizon that does not exist, so every non-L4 shape is ground); a shape's effective shift is S_all + S_group | 21 |
| `11100` | **STATUS** | arm_src2 and bkt_src2 (0 = none/S4, 1 = static/S0, 2 = sensed/S1, 3 = estimated/S2–S3, §5.3), arm7 (angle = code − 30°, so −30..+97°), bkt7 (bucket relative to the arm, (code − 64)·1.5°, so −96..+94.5°), conf2 (0 = unbounded, the S3 band; 1 low; 2 medium; 3 high), corr_n3 (corridor anomalies detected, 7 = ≥ 7, *even if not yet sent*), mask_anom1, moving1 (1 = true) | 30 |
| `11101` | **ANOM** | slot3 (id 80+slot), x6 y5 (top-left corner, 8 px grid), w3 h3 ((v+1)·8 px), RGB444 12. A box define that a later POLY with the same id may refine. | 37 |
| `11110` | **BLOB** (L4) | id7, centre 13 (4 px grid, x7 y6), rx3, ry3 ((v+1)·4 px), rot3 (rotation of the rx axis, 0..157.5° in 22.5° steps), FILL | 40–54 |
| `111110` | **SKYLINE** | n2 (8 / 12 / 16 / 24 samples), sc2 (height unit ×4 / ×8 / ×16 / ×32 px), n × 3-bit heights h_i = code·unit above the horizon line at x_i = (i + 0.5)·384/n, joined by straight segments; FILL for the band between the horizon and the profile. A singleton of L0: a new SKYLINE replaces the old one, and it is never CONFIRMed | 8 samples 48; 12 samples 60; 16 samples 72; 24 samples 96 |
| `111111` | **EXT** + sub4 | See the EXT subtypes below | 12–69 |

**HZN modes**

| Mode | Fields | Size |
|---|---|---|
| 00 ABS | y8 (2 px, y = 2v − 128 at x = 192, so −128..+382 px, which covers a horizon above or below the frame), ang6 (0.5° steps, −16..+15.5°), curv4 (signed sag at the frame edge, 4 px steps, −32..+28 px; 0 after calibration), SKY vfill, GND vfill | 42–58 |
| 01 RESID | dy5 (2 px, −32..+30 px), dang4 (0.5°, −4..+3.5°). **Relative to the current epoch's ABS** (Phase 3: to the IMU prediction for that capture), never to a previous RESID; not sent while the epoch's anchor is NO_HORIZON | 15 |
| 10 COLOURS | 2 × vfill | 24–40 |
| 11 NO_HORIZON | top and bottom vfill. An absolute anchor like ABS: it starts an epoch and completes a hand-over (§4.3) | 24–40 |

**EXT subtypes**

| Sub | Record | Fields | Size |
|---|---|---|---|
| 0 | INSERT | id7 (a POLY), edge4 (define edge 0..n−1; edge e runs from define vertex e to e+1 mod n), k2 (order within that edge), EG2 (dx, dy) from **the define-edge midpoint** in the define's grid | 29–35, typically 31 (est.) |
| 1 | CONFIRM | base_id7, cnt4 (= count − 1, so 1..16), mask[cnt] (bit i ↔ id base_id + i, first bit first), then tag2 for each set bit in that order | 21 + cnt + 2·set; 69 for 16 of 16 |
| 2 | DIGEST | n_live7, crc8 over the live shapes sorted by id ascending, each serialised as `id u8, define-hash u16le, state-hash u16le`, followed by the epoch's render state — the four GSHIFT groups in grp2 order (far, ground, all, L4) as `dx s8, dy s8` (the record's 2 px codes), the GZOOM code `u8`, then the three GAIN codes `u8` — where state-hash is CRC-16/CCITT-FALSE over the shape's full live state: `local offset dx s8, dy s8 (grid cells), base colour RGB444 u16le, n_inserts u8, the INSERT records' packed bytes in canonical (edge, k) order, then the four HOLE slots as (present u8, centre u16le, r u8)`. The input is canonical (arrival order never matters) and complete (a lost GSHIFT, GZOOM or GAIN mismatches it), so a stale state changes the DIGEST input with probability 1 − 2⁻¹⁶ and the aggregate CRC-8 bounds a false pass at 1/256. CRC-8 is poly 0x07, init 0x00, no reflection, xorout 0x00 (check value of "123456789" = 0xF4); golden vector: one shape with define-hash 0x1234 and state-hash 0x5678 and a neutral render state (no shifts, GZOOM 0x80, GAIN 0x10 × 3), `2A 34 12 78 56 00 00 00 00 00 00 00 00 80 10 10 10` → 0xD2. define-hash is CRC-16/CCITT-FALSE (poly 0x1021, init 0xFFFF, no reflection) over the define record's packed bytes, prefix code through FILL, zero-padded to a byte | 25 |
| 3 | LAYER_CLEAR | range2: 0 = L1–L4, 1 = L2–L4, 2 = L3–L4, 3 = L4 only (M and L0 are never cleared). It is idempotent per (epoch, range): the store remembers the last pair it applied and ignores a repeat of it, so the repeat-once of §3.1 re-sends the anchor and the clear without erasing what the first epoch frame already defined; a *different* range in the same epoch empties those layers of the current epoch at once. In an epoch-start frame it names the layers the new epoch rebuilds from scratch: at hand-over (§4.3) the previous epoch's cached shapes in those layers are dropped and shapes in the other layers are carried into the new epoch with their IDs and ages until redefined or TTL'd — a camera change, ID exhaustion or entering VECTOR sends 0; the 60 s safety refresh of a static scene sends 2 or 3 and re-anchors without re-sending the masses | 12 |
| 4 | CAL_REV | cal16, mask16 (low 16 bits of the SHA-256 hashes) | 42 |
| 5 | PAL | slot3 (adaptive slots 8–15), RGB444 12 | 25 |
| 6 | GZOOM | u8 code z for the signed ground-motion parameter of §4.4: u = (z − 128) / 4096 px⁻¹ (z = 128 → 0; ±127 codes = ±0.031 px⁻¹, about ±5 m of travel at 130° with h = 1.8 m and ±30 m at 39°; one code ≈ 4 cm / 23 cm), cumulative since the epoch start, not a delta; the renderer applies r′ = r / (1 − u·r) with x scaled by r′/r about the vanishing point, so reversing (u < 0) contracts the ground; a value outside the field starts a new epoch | 18 |
| 7 | GAIN | 3 × 5-bit per-channel code g: gain = 2^((g − 16) / 32) (neutral 16; 2.2 % per code; 0 → ×0.71, 31 → ×1.38), absolute since the epoch start, applied to each 8-bit channel of the base colour and clipped to 0–255 | 25 |
| 8 | HOLE | parent id7, slot2 (0–3 per parent), del1, centre 13 (4 px), r3 ((v+1)·4 px). A HOLE for an existing slot replaces it; del1 = 1 removes it (centre and r ignored). Holes have no identity beyond their slot: they live and die with the parent and are part of its state-hash, so CONFIRM and DIGEST cover them | 36 |
| 9–15 | reserved | Reject frame | — |

**FILL** = `m1 | (pal4 if m = 0, else RGB444 12) | g1 | [dir3 (22.5° steps over 180°) | dl3]`. `dl3` is a two's-complement code c ∈ −4..+3 giving ΔL = 16·c in 8-bit units (−64..+48): the colour at the shape's bounding-box extreme in direction `dir3` is the base colour + ΔL on every channel and at the opposite extreme base − ΔL, linear between, each channel clipped to 0–255 (the RGB444 base is scaled ×17 to 8 bits first).

| Fill | Bits |
|---|---|
| Palette, flat | 6 |
| Palette, gradient | 12 |
| RGB, flat | 14 |
| RGB, gradient | 20 |

**vfill** (HZN only) = `m1 | pal4 or rgb12 | dl4 (vertical)`, 9 or 17 bits; `dl4` is a two's-complement code c ∈ −8..+7 with ΔL = 8·c (−64..+56): for either band, base + ΔL at the band's top edge and base − ΔL at its bottom edge — the sky band is +ΔL at the frame top and −ΔL at the horizon, the ground band +ΔL at the horizon and −ΔL at the frame bottom — clipped the same way.

- **Palette.**
  - Slots 0–7 are a static farm palette pinned in the codec as RGB444: 0 sky `0x6BE`, 1 overcast `0xBBC`, 2 dark foliage `0x252`, 3 light foliage `0x693`, 4 straw `0xDB6`, 5 soil `0x753`, 6 shadow `0x223`, 7 white `0xFFF` (a golden vector renders all eight).
  - Slots 8–15 are set adaptively by PAL.
  - Use `m = 0` only if the slot is within ΔE76 ≤ 4 of the measured mean.
- **Gradient.** The renderer sets the endpoint colours to base ± ΔL (the `dl3` rule above) along `dir` through the centroid, spanning the shape's projected extent. Colours are multiplied by the epoch GAIN.

**Vertex coding: EG2 zigzag per axis.** Each delta d (grid cells) is zigzag-mapped to v = 2d for d ≥ 0 and v = −2d − 1 for d < 0, then written as order-2 Exp-Golomb: with w = v + 4, emit ⌊log₂ w⌋ − 2 zero bits followed by w in binary. The encoder never emits more than four leading zeros (v ≤ 123); a decoder that reads five rejects the frame (§3.4).

| Zigzag value | Bits |
|---|---|
| 0..3 | 3 |
| 4..11 | 5 |
| 12..27 | 7 |
| 28..59 | 9 |
| 60..123 | 11 |

**Coordinate ranges.**

- **v0:**
  - 8 px grid: x6 (0..47), y5 (0..31), 11 bits.
  - 4 px grid: x7 (−16..111, with horizontal margin), y6 (0..63), 13 bits.
  - v0's y is always in the frame; later vertices may lie outside via their deltas, and the renderer clips.
- **Epoch-stabilised coordinates:** q = p − S_group(epoch). The base draws at q + S_latest, so a lost GSHIFT or GZOOM only lags the offset.
- **Grid to pixels:** px = gx·8, py = gy·8 on the 8 px grid (W × H = 48 × 32 cells) and px = gx·4, py = gy·4 on the 4 px grid (96 × 64 cells); W and H are the grid's cell counts, never the 12 × 8 tile grid of the `TileDeltaFrame` header.

**Order-independent INSERT (resolves review issues b3 and s6).**

- INSERT names a *define* edge e (the fixed vertices of the define) and an order k within that edge, and positions itself relative to that define edge's midpoint. Its meaning therefore never depends on which other INSERTs arrived.
- The base builds the ring as: define vertices in order, then, within each edge e, the received INSERTs sorted by k.
- **Any subset** of INSERTs gives a sub-ring of the canonical full ring, which is a valid VW simplification.
- The encoder allows at most 4 INSERTs per define edge; beyond that it redefines.
- A re-sent define with the same define-hash keeps the INSERTs. A new define-hash clears them.

### 3.4 Parser rules (base; fuzz-tested)

1. If byte0 bit7 ≠ 0 or V ≠ 0, drop the frame and count it.
2. **Before each record, if every remaining bit is 0, stop successfully (padding).** No valid record is all zeros, because id 0 is illegal on every record that carries an id. Otherwise decode the record.
3. **Drop the whole frame** on any of:
   - a truncated record whose remaining bits are not all zero;
   - a reserved EXT subtype, EDGE cls, or version;
   - an id outside its range (masses 1–31, plants 32–55, edges 56–79, corridor 80–87, L4 88–127; POLY is also legal on 80–87);
   - id 0;

   The fragment has already passed the L072's payload CRC and the reassembler, so a parse error means version skew or a bug. Rejecting the whole frame keeps the store deterministic.
4. UPD, UCOL, INSERT, DEL, CONFIRM or HOLE naming an unknown id is an *orphan*: ignore it and count it.
5. **Per-field last writer wins by capture time.** Each shape has five fields, each with its own capture time:

   | Field | Set by |
   |---|---|
   | geometry | define + INSERTs |
   | local offset | UPD (per shape) |
   | group shift | GSHIFT (per group) |
   | group zoom | GZOOM (per group) |
   | base colour | define fill, UCOL (per shape) |
   | gain | GAIN (per frame, all shapes) |

   Each row is its own last-writer-wins state with its own clock, so a GSHIFT never discards a shape's UPD and a GAIN never replaces a UCOL. On screen: vertices → local offset → group shift → group zoom (about the ground anchor) → screen, and colour = gain × base colour. Group transforms are absolute values, not accumulated deltas; every define stores the group transform current at its capture time and the renderer applies (group now − group at define), so a redefine at the current position never double-shifts. A define with an unchanged define-hash refreshes only the geometry age and never resets the other four. A new define-hash is a redefine at the current position, so the local offset is set to 0 at that define's capture time.

### 3.5 Epochs (revised acceptance)

A frame is applied, or switches the base to its epoch, when any of these holds:

1. its epoch equals the current epoch;
2. K = 1 and its capture time is later than the last applied capture time (this covers a tractor reboot and a normal epoch start);
3. its epoch is 1..7 ahead (mod 16);
4. no frame has been applied for more than 3 s, which covers any wrap during an outage;
5. it is the third consecutive "behind" frame with a strictly increasing capture time (self-heal).

Otherwise the frame is dropped and `vs_epoch_behind` is counted.

- **Hand-over.** The old epoch stays visible as **CACHED (1)** (desaturated, outline-weighted) until the new epoch's absolute HZN (ABS, or NO_HORIZON when the camera points down) has arrived and ≥ 50 % of its DIGEST `n_live` shapes are present. Only the DIGEST half of that condition times out (after 2 frames the store shows what it has); the absolute-HZN half never does, because without an anchor there is nothing to hand over to — if both epoch-start copies are lost, the cached picture stays until the tractor's next epoch start (the repeat-once copy, or the ≤ 60 s safety refresh). There is no black flash. At hand-over, old-epoch shapes in the layers named by the epoch start's LAYER_CLEAR are dropped and the rest are carried into the new epoch with their IDs and ages (§3.3).
- **Key frames.** The first frame of an epoch is an absolute HZN — ABS, or NO_HORIZON when the camera points down (§2.4) — plus LAYER_CLEAR when it fits (58 + 12 = 70; 40 + 12 = 52 for NO_HORIZON). `image_tx_daemon` sends it twice when its own cumulative TX-failure ratio exceeds 0.5 % (§3.1) — a local counter that cannot see air loss, which is why VS1 repeats the epoch start itself (§4.3).

### 3.6 Worked byte counts: typical field-edge scene, cold start, static

**Scene content: 23 records, 1,018 record bits (a 129 B VS body with the 13-bit header; computed from the §3.3 sizes, INSERT taken as 31 bits est.)**

| Records | Bits each | Total |
|---|---|---|
| HZN ABS (RGB vfills) | 58 | 58 |
| STATUS | 30 | 30 |
| Near and far fields (gradient triangles) | 69 | 138 |
| 12-sample treeline SKYLINE | 60 | 60 |
| Track, shed wall, roof (flat RGB triangles) | 63 | 189 |
| 2 isolated trees (no trunks at 130°) | 42 | 84 |
| 1 shrub | 42 | 42 |
| Fence EDGE (3 segments) | 64 | 64 |
| 2 rut EDGEs | 40 | 80 |
| DIGEST | 25 | 25 |
| 8 INSERTs (triangles → quads and pentagons) | 31 | 248 |

The hood is masked (0 bits). The bucket is always encoded as ordinary scene shapes (§5).

**Packing (computed).** The whole scene, key frame included, fits in **one frame** at either profile: 1,018 of 1,563 bits at FHSS (545 spare ≈ 17 more INSERTs) and 1,018 of 1,883 bits at DTS (865 spare). On air that first frame is 147 B (129 B VS body): 120.4 ms at FHSS, 60.2 ms at DTS. With the epoch-start duplicate that `image_tx_daemon` adds when its local TX-failure ratio exceeds 0.5 %, the cold start costs two frames.

**Time to first picture:** one camera period (500 ms at 2 fps) plus the frame's airtime plus the base's reassembly and publish path. Compared with `mono_g4`, which needs several 243 B frames to rotate through 96 tiles, VS1 shows the full scene on the first frame.

**Steady state (est.)**

| Case | Records | Bits | Share of a DTS frame |
|---|---|---|---|
| Pan | 2 GSHIFT + 3 UPD + RESID = 42 + 51 + 15 | 108 | 6 % |
| Forward drive | GSHIFT far + GSHIFT ground + GZOOM + RESID + 3 UPD + 1 near-field redefine | ≈ 195 | 10 % |
| Static | CONFIRM + DIGEST keep ages honest; the rest goes to INSERT, HOLE and L4 until the residual floor, then frames shrink to ≈ 12 B | — | — |

A moving scene therefore leaves most of every frame for repeat-once, the carousel and new detail; §4.2 gives the budget order.

### 3.7 Budget per profile and what changes it

| Profile | Fragment body | VS body F | Notes |
|---|---|---|---|
| p0 `BENCH_ONLY_FIXED_915` | 203 B | 197 B | Bench only; same modem tuple as p1 without hopping (`SETTINGS_REFERENCE.md` §2.1) |
| p1 `FCC_15_247_FHSS_50CH_BW250` | 203 B | 197 B | One fragment per 200 ms slot; commands steal slots |
| p2 `FCC_15_247_DTS_BW500` | 243 B | 237 B | 99.9 ms per full frame; commands ride the pacing gaps |
| any, with D14 split-trust switched on | −6 B | −6 B | 4 B seq + 2 B CRC32 per fragment (`LORA_PROTOCOL.md` priority-class table) |

The encoder takes F from the live `tractor/link_budget` value minus the 6 B `TileDeltaFrame` header — the topic carries the whole payload budget (203/243 B), and `camera_service` already charges its fixed header against it (`x8/camera_service.py:1066-1075`) — so a profile switch (two-phase `0x65/0x66/0x67`, `bs/image_rx_daemon.py:200-205`, opcodes `bs/lora_proto.py:958-960`) changes the frame size on the next capture with no format change. Airtime is quantised in 3.5 B steps (1.28 ms at BW500, 2.56 ms at BW250), so the packer rounds a frame down to the last whole step rather than padding.

---

## 4. Temporal and refresh behaviour

### 4.1 Refresh loop

- The encoder runs once per camera capture (2 fps by default, `x8/camera_service.py:109`; the interval is a setting) on the **newest** frame and emits **one** `TileDeltaFrame` of codec 6 on MQTT `cmd/image_frame`, exactly where `_build_frame` publishes tile frames today (`x8/camera_service.py:1576-1617`).
- `image_tx_daemon` paces by time-on-air with 0.92 headroom (`x8/image_tx_daemon.py:355-411`) and drops the oldest queued frame when its 4-deep queue is full (`:559-574`). VS1 therefore never queues more than one frame: if the previous frame is still waiting (queue depth from the daemon's `tractor/link_rx` status topic, §7.1), the encoder skips this capture and folds its changes into the next one.
- On FHSS each frame takes one 200 ms slot, so at 2 fps VS1 uses two of every five slots and base commands steal from the rest. On DTS a full frame is 99.9 ms, so two frames per second are 20 % of airtime.
- Frames are sized to the retained `tractor/link_budget` (203 or 243 B). A quiet scene shrinks its frames to a few bytes rather than padding (§3.7).

### 4.2 Budget order within a frame

1. Epoch-start records when an epoch starts (§3.5): the absolute HZN (ABS or NO_HORIZON) + LAYER_CLEAR.
2. ANOM, if corr_n > 0.
3. HZN (RESID, or ABS when an epoch starts or a stop changes by ΔE > 6), GSHIFT, GZOOM, GAIN.
4. STATUS (every frame while the arm moves or `mask_anom = 1`; otherwise every 4th frame or on change).
5. Changes (new, UPD, UCOL, DEL, HOLE), by ΔD/bit.
6. Repeat-once of the previous frame's defines, **re-verified**.
7. Carousel (κ = 25 % of the remaining budget), **re-verified**.
8. CONFIRM and DIGEST.
9. INSERT and L4, until the budget or the residual floor.

With 1,563–1,883 record bits per frame, items 1–5 rarely exceed a third of the frame even while driving; the rest is repeat-once, carousel and detail. There are no frame templates: the packer is the CELF greedy of §2.9 with this priority order as a pre-sort.

**Static accumulation.** With `moving = 0`, change bits fall to about 0. Detail accumulates at roughly 40–50 INSERT/HOLE/L4 records per frame (est.) until the residual threshold. After it, most frames are the 12 B floor — anchor + CONFIRM, 83 record bits: room for the RESID anchor, one CONFIRM or DIGEST and at most one small record, so no carousel — and every fourth frame at V0 (κ = 25 %) is a ≈ 40 B carousel frame carrying about four defines. At 2 fps that is 3 × 18.0 + 28.2 ms per 2 s (4.1 % of DTS airtime; 3 × 36.0 + 56.4 ms, 8.2 %, on FHSS), which is what the carousel age bound of §4.1 costs; the channel is otherwise free for commands.
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

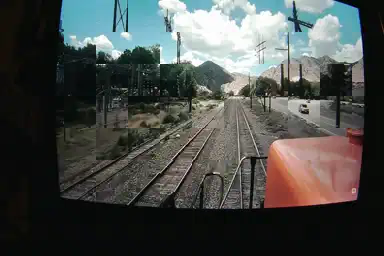
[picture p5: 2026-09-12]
LifeTrac-v25/DESIGN-CONTROLLER/bench-evidence/RS_3_3_long_train_leg_2026-09-07/long_leg_canvas_midmotion_20260907.png

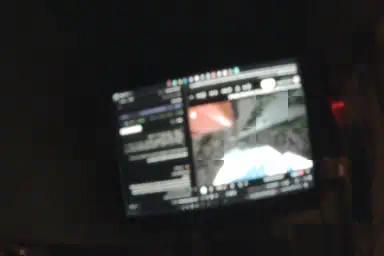
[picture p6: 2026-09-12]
LifeTrac-v25/DESIGN-CONTROLLER/bench-evidence/RS_3_3_motion_leg_2026-09-06/motion_leg_canvas_20260906.png

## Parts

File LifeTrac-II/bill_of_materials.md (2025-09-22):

# LifeTrac II - Bill of Materials

This document contains the bill of materials information for LifeTrac II.

## Overview

LifeTrac II features a modular design with detailed parts sourcing and hydraulic system components.

## Detailed Resources

The complete bill of materials for LifeTrac II is available in the following resources:

### Part Sourcing
- **Link:** [LifeTrac II Part Sourcing](https://wiki.opensourceecology.org/wiki/LifeTrac_II_Part_Sourcing)
- **Contents:** Detailed Bill of Materials and instructional videos

### Hydraulics BOM  
- **Link:** [LifeTrac II Hydraulic Parts List](https://wiki.opensourceecology.org/wiki/LifeTrac_II_(shortened)_hydraulic_parts_list)
- **Contents:** Shortened bill of materials specifically for the hydraulics system

### Material Costs
- **Link:** [LifeTrac II Bill of Materials](https://wiki.opensourceecology.org/wiki/LifeTrac_II_Bill_of_Materials)  
- **Contents:** Complete materials cost breakdown for the LifeTrac II build

## Key Components

- 2x Power Cubes (modular engine units)
- Hydraulic system components
- Front-end loader assembly
- Rear-end loader assembly
- Skid steer chassis components
- Track and tire assembly

## Notes

For the most up-to-date and detailed parts information, please refer to the wiki links above as they contain comprehensive lists with part numbers, suppliers, and current pricing.

## Related Documents

- [LifeTrac II README](README.md) - General information about this version

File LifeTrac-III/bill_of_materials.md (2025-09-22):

# LifeTrac III - Bill of Materials

This document contains the bill of materials information for LifeTrac III.

## Overview

LifeTrac III features a comprehensive bill of materials as part of the Civilization Starter Kit DVD v0.01 documentation package.

## Documentation Status

**Note:** As of 2011, the Bill of Materials was created but completeness and accuracy were under review.

## Detailed Resources

The complete bill of materials for LifeTrac III is available in the following resources:

### Primary BOM Resource
- **Document:** [Tractor Bill of Materials](https://wiki.opensourceecology.org/wiki/Tractor_Bill_of_Materials)
- **Source:** Civilization Starter Kit DVD v0.01 (Section 4.3)
- **Contents:** Comprehensive parts listing for LifeTrac III construction

### Supporting Documentation
- **CAD Files:** [Tractor Master CAD File](https://wiki.opensourceecology.org/wiki/Tractor_Master_CAD_File)
- **Fabrication:** [Tractor Fabrication Manual](https://wiki.opensourceecology.org/wiki/Tractor_Fabrication_Manual)
- **Assembly:** [Tractor Assembly](https://wiki.opensourceecology.org/wiki/Tractor_Assembly) (includes 12-minute assembly video)
- **Quality Control:** [LifeTrac Quality Control Checklist](https://wiki.opensourceecology.org/wiki/File:LifeTrac_Quality_Control_Checklist.pdf)

## Key Component Categories

- **Hydraulic Motors:** 32 cu in hydraulic motors
- **Hydraulic System:** Quick attach valves and related components
- **Loader Assembly:** Single front-end loader components
- **Power System:** Modular Power Cube components
- **Chassis:** Skid steer frame and support structure
- **Controls:** Hydraulic controls with quick connects

## Fabrication Resources

- [Fabrication Drawings](https://wiki.opensourceecology.org/wiki/File:Open_Source_Ecology_-_LifeTrac_-_Fabrication_Drawings.pdf)
- [Fabrication Manual](https://wiki.opensourceecology.org/wiki/Tractor_Fabrication_Manual)

## Notes

This version marked the introduction of quick attach valves, which became a standard feature in subsequent LifeTrac versions. The bill of materials reflects the transition to more modular hydraulic components.

## Related Documents

- [LifeTrac III README](README.md) - General information about this version
- [Tractor User Manual](https://wiki.opensourceecology.org/wiki/Tractor_User_Manual) - Operation instructions

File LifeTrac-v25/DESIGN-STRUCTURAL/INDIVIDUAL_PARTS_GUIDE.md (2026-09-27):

# Individual Part SVG Export Guide

## Overview

Eight of the LifeTrac v25 flat plate designs have their own export file, and this guide generates a 2D SVG cutout of each for CNC plasma cutting. They are not every plate in the machine: the bucket back, the stiffener plates and the motor plates are only drawn inside the main assembly, and the arm plates and pivot-mount plates have no export file yet (review finding M21).

> [!WARNING]
> These parts are not yet ready for fabrication. Read the warning at the top of [README.md](README.md) before cutting anything.

## Quick Start

### Generate All Individual SVGs

```bash
cd LifeTrac-v25/DESIGN-STRUCTURAL
./export_individual_svgs.sh
```

SVG files will be created in `output/svg/parts/`

### Generate Single Part SVG

```bash
cd LifeTrac-v25/DESIGN-STRUCTURAL
mkdir -p output/svg/parts
openscad -o output/svg/parts/wheel_mount.svg --export-format=svg openscad/parts/export_wheel_mount.scad
```

## Part List

### Half-Inch (1/2" = 12.7mm) Plate Parts

| Part Name | Export File | Output SVG | Qty | Dimensions |
|---|---|---|-----|---|
| Side Panel Outer | `export_side_panel_outer.scad` | `side_panel_outer.svg` | 2 | ~1400×1000mm |
| Side Panel Inner | `export_side_panel_inner.scad` | `side_panel_inner.svg` | 2 | ~1400×1000mm |
| Wheel Mount | `export_wheel_mount.scad` | `wheel_mount.svg` | 4 | 250×250mm |
| Cylinder Lug | `export_cylinder_lug.scad` | `cylinder_lug.svg` | 6 | 100×150mm |
| Rear Crossmember | `export_rear_crossmember.scad` | `rear_crossmember.svg` | 1 | Variable |

### Quarter-Inch (1/4" = 6.35mm) Plate Parts

| Part Name | Export File | Output SVG | Qty | Dimensions |
|---|---|---|-----|---|
| Standing Deck | `export_standing_deck.scad` | `standing_deck.svg` | 1 | 700×400mm |
| Bucket Bottom | `export_bucket_bottom.scad` | `bucket_bottom.svg` | 1 | 1100×600mm |
| Bucket Side | `export_bucket_side.scad` | `bucket_side.svg` | 2 | ~450×600mm |

**Total: 19 parts from 8 unique designs**

## Part Features Included

All individual SVG exports include:

### Structural Features
- ✅ **Rounded corners** (6.35-10mm radius per design)
- ✅ **Proper dimensions** in millimeters
- ✅ **Lightening holes** where applicable (weight reduction)

### Mounting Features
- ✅ **Bolt holes** with clearances
  - 1/2" bolt holes: 14.7mm (12.7mm + 2mm clearance)
  - 3/4" bolt holes: 21.05mm (19.05mm + 2mm clearance)
  - 1" bolt holes: 27.4mm (25.4mm + 2mm clearance)
- ✅ **Corner mounting holes** for panel attachment
- ✅ **Edge mounting holes** for assembly

### Operational Features
- ✅ **Pivot holes** (38.1mm for 1.5" pins)
- ✅ **Arc slots** for cross beam clearance (inner panels only)
- ✅ **Motor mounting bolt patterns** (wheel mounts)
- ✅ **Anti-slip hole patterns** (standing deck)
- ✅ **Hydraulic cylinder pivot holes** (lugs)

## Usage Instructions

### For CNC Plasma Cutting

1. **Load SVG** into your CAM software (e.g., SheetCAM, Torchmate CAD)
2. **Verify dimensions** - all measurements in millimeters
3. **Set kerf compensation** - typically 1-2mm for plasma cutting
4. **Add lead-ins/lead-outs** - 5-10mm approach paths
5. **Set pierce delays** appropriate for material thickness
6. **Generate G-code**

### Material Specifications

#### 1/2" Plate Parts (ASTM A36 or equivalent)
- Thickness: 12.7mm
- Parts: Side panels, wheel mounts, cylinder lugs, rear crossmember
- Total area: ~11.6 m² (calculate from SVG files)

#### 1/4" Plate Parts (ASTM A36 or equivalent)
- Thickness: 6.35mm  
- Parts: Standing deck, bucket bottom, bucket sides
- Total area: ~2.5 m² (calculate from SVG files)

### Assembly Notes

#### Side Panels
- **Outer panels**: 2× identical (left/right are same, just flip)
- **Inner panels**: 2× identical with arc slots for cross beams
- Install with sandwich spacing of 120mm between inner/outer

#### Wheel Mounts
- 4× identical plates
- Positions: Front Left, Front Right, Rear Left, Rear Right
- Install with motor shaft centered through hub hole

#### Cylinder Lugs
- 6× identical lugs used for:
  - 2× Lift cylinder base mounts
  - 2× Bucket cylinder mounts
  - 2× Bucket attachment points

#### Bucket Sides
- 2× required (use same SVG, mirror for opposite side)
- Trapezoidal shape tapers from front to back

## File Structure

```
DESIGN-STRUCTURAL/
├── openscad/
│   └── parts/
│       ├── side_panel.scad                # Part definition
│       ├── export_side_panel_outer.scad   # 2D export wrapper
│       ├── export_side_panel_inner.scad   # 2D export wrapper
│       ├── wheel_mount.scad               # Part definition
│       ├── export_wheel_mount.scad        # 2D export wrapper
│       └── ... (other parts)
├── output/                                # Generated locally, git-ignored
│   └── svg/
│       └── parts/
│           ├── side_panel_outer.svg       # Generated SVG
│           ├── side_panel_inner.svg       # Generated SVG
│           ├── wheel_mount.svg            # Generated SVG
│           └── ... (other SVGs)
└── export_individual_svgs.sh              # Batch export script
```

## Automated Generation

The GitHub Actions workflow `.github/workflows/generate-part-svgs.yml` runs on pull requests and pushes to `main` that change `openscad/parts/*.scad` or `openscad/lifetrac_v25_params.scad`. It:
- Regenerates the 8 individual part SVGs listed above
- Fails if any SVG is missing or empty
- Uploads the SVGs as the `part-svgs` workflow artifact, kept for 90 days

It does not commit the SVGs or edit the README, because `output/` is git-ignored.

## Troubleshooting

### SVG file is empty or missing features
- Ensure OpenSCAD is installed: `openscad --version`
- Check that parameters file is accessible: `openscad/lifetrac_v25_params.scad`
- Verify projection is set to `cut=true` in export file

### Dimensions are wrong
- All dimensions are in millimeters by default in OpenSCAD
- Verify your CAM software is set to metric units
- Check viewBox attribute in SVG for scale

### Holes are too small/large
- Hole sizes include 2mm clearance for bolts
- Adjust clearance in part .scad files if needed
- Remember to account for kerf in CAM software

## Contributing

When adding new plate parts:

1. Create the part file: `openscad/parts/new_part.scad`
2. Create export wrapper: `openscad/parts/export_new_part.scad`
3. Add it to the export script `export_individual_svgs.sh` and to the export list in `.github/workflows/generate-part-svgs.yml`
4. Update this guide with part specifications
5. Test SVG generation before committing

## See Also

- `openscad/parts/README_EXPORTS.md` - Detailed export file documentation
- `openscad/cnclayout.scad` - Combined layout of all parts
- `openscad/lifetrac_v25.scad` - Full assembly model
- `openscad/lifetrac_v25_params.scad` - Shared parameters

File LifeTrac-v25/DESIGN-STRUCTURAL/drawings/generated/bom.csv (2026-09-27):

id | name | category | stock | qty_per_machine | qty_source | size | mass_each_kg | mass_total_kg | holes | rev | geometry_id | drawing | flat_pattern
P1 | Side panel, outer, left | plate | PL 1/2 [12.7] ASTM A36 | 1 | model | 1392.6 x 1000 | 82.84 | 82.84 | 24 | B | 4123def0 | pdf/P1_side-panel-outer-left.pdf | dxf/P1_side-panel-outer-left.dxf
P2 | Side panel, outer, right | plate | PL 1/2 [12.7] ASTM A36 | 1 | model | 1392.6 x 1000 | 82.84 | 82.84 | 24 | B | 6363acb3 | pdf/P2_side-panel-outer-right.pdf | dxf/P2_side-panel-outer-right.dxf
P3 | Side panel, inner | plate | PL 1/2 [12.7] ASTM A36 | 2 | model | 1349.2 x 968.2 | 75.70 | 151.41 | 30 | B | b5b07b32 | pdf/P3_side-panel-inner.pdf | dxf/P3_side-panel-inner.dxf
P4 | Back stiffener plate | plate | PL 1/4 [6.35] ASTM A36 | 1 | model | 1020 x 650 | 32.97 | 32.97 | 24 | A | e035d508 | pdf/P4_back-stiffener-plate.pdf | dxf/P4_back-stiffener-plate.dxf
P5 | Front stiffener plate, centre | plate | PL 1/4 [6.35] ASTM A36 | 1 | model | 481.6 x 260.4 | 6.22 | 6.22 | 4 | C | e8eb53fc | pdf/P5_front-stiffener-plate-centre.pdf | dxf/P5_front-stiffener-plate-centre.dxf
P6 | Front stiffener plate, outer | plate | PL 1/4 [6.35] ASTM A36 | 2 | model | 269.2 x 127 | 1.68 | 3.35 | 8 | A | ce46ccb4 | pdf/P6_front-stiffener-plate-outer.pdf | dxf/P6_front-stiffener-plate-outer.dxf
P7 | Bottom stiffener plate | plate | PL 1/4 [6.35] ASTM A36 | 1 | model | 1196.8 x 1020 | 60.57 | 60.57 | 80 | A | d57bacba | pdf/P7_bottom-stiffener-plate.pdf | dxf/P7_bottom-stiffener-plate.dxf
P8 | Motor mounting plate | plate | PL 1/4 [6.35] ASTM A36 | 2 | model | 1196.8 x 254 | 14.13 | 28.26 | 10 | A | 4a77954d | pdf/P8_motor-mounting-plate.pdf | dxf/P8_motor-mounting-plate.dxf
P9 | Arm side plate, inner | plate | PL 1/4 [6.35] ASTM A36 | 2 | model | 1792 x 350.1 | 13.21 | 26.42 | 21 | A | c66393d2 | pdf/P9_arm-side-plate-inner.pdf | dxf/P9_arm-side-plate-inner.dxf
P10 | Arm side plate, outer | plate | PL 1/4 [6.35] ASTM A36 | 2 | model | 1792 x 350.1 | 13.62 | 27.24 | 17 | A | cd282970 | pdf/P10_arm-side-plate-outer.pdf | dxf/P10_arm-side-plate-outer.dxf
P11 | Arm pivot mount plate | plate | PL 1/4 [6.35] ASTM A36 | 4 | model | 152.3 x 152.3 | 0.78 | 3.10 | 6 | A | 5a8028c0 | pdf/P11_arm-pivot-mount-plate.pdf | dxf/P11_arm-pivot-mount-plate.dxf
P12 | Bucket back plate | plate | PL 1/4 [6.35] ASTM A36 | 1 | model | 1112.7 x 450 | 24.66 | 24.66 | 0 | A | c3db581c | pdf/P12_bucket-back-plate.pdf | dxf/P12_bucket-back-plate.dxf
P13 | Bucket bottom plate | plate | PL 1/4 [6.35] ASTM A36 | 1 | model | 1112.7 x 600 | 32.79 | 32.79 | 0 | A | 7302a2b0 | pdf/P13_bucket-bottom-plate.pdf | dxf/P13_bucket-bottom-plate.dxf
P14 | Bucket side plate | plate | PL 1/4 [6.35] ASTM A36 | 2 | model | 600 x 450 | 8.83 | 17.66 | 0 | A | 61d042e5 | pdf/P14_bucket-side-plate.pdf | dxf/P14_bucket-side-plate.dxf
P15 | Platform deck | plate | PL 1/4 [6.35] ASTM A36 | 1 | model | 735.5 x 400 | 14.30 | 14.30 | 42 | A | e755d2b1 | pdf/P15_platform-deck.pdf | dxf/P15_platform-deck.dxf
P16 | Platform pivot bracket | plate | PL 1/4 [6.35] ASTM A36 | 2 | model | 400 x 230 | 2.45 | 4.90 | 4 | A | 77336b8c | pdf/P16_platform-pivot-bracket.pdf | dxf/P16_platform-pivot-bracket.dxf
P17 | Wheel hub lug plate | plate | PL 1/2 [12.7] ASTM A36 | 4 | model | 228.6 x 228.6 | 3.71 | 14.86 | 9 | A | ba3b4756 | pdf/P17_wheel-hub-lug-plate.pdf | dxf/P17_wheel-hub-lug-plate.dxf
P18 | Wheel hub gusset | plate | PL 1/4 [6.35] ASTM A36 | 16 | model | 86.4 x 83.9 | 0.18 | 2.89 | 0 | A | 81082eca | pdf/P18_wheel-hub-gusset.pdf | dxf/P18_wheel-hub-gusset.dxf
P19 | Bucket cutting edge | plate | PL 3/4 [19.05] ASTM A36 | 1 | model | 1100 x 80 | 13.16 | 13.16 | 0 | A | 2e34993a | pdf/P19_bucket-cutting-edge.pdf | dxf/P19_bucket-cutting-edge.dxf
A1 | Back stiffener outer vertical angle | angle | L2x2x1/4 ANGLE (2" x 2" x 1/4"), ASTM A36 | 2 | model | 650 [~25-9/16"] | 3.06 | 6.12 | 8 | A | 1c18978d | pdf/A1_back-stiffener-outer-vertical-angle.pdf
A2 | Back stiffener inner vertical angle | angle | L2x2x1/4 ANGLE (2" x 2" x 1/4"), ASTM A36 | 4 | model | 650 [~25-9/16"] | 3.06 | 12.23 | 8 | A | 1c18978d | pdf/A2_back-stiffener-inner-vertical-angle.pdf
A4 | Frame tube mount angle | angle | L2x2x1/4 ANGLE (2" x 2" x 1/4"), ASTM A36 | 26 | model | 146.1 [5-3/4"] | 0.67 | 17.38 | 4 | A | 767f5c4c | pdf/A4_frame-tube-mount-angle.pdf
A5 | Arm crossbeam mount angle | angle | L2x2x1/4 ANGLE (2" x 2" x 1/4"), ASTM A36 | 4 | model | 146.1 [5-3/4"] | 0.67 | 2.67 | 4 | A | 767f5c4c | pdf/A5_arm-crossbeam-mount-angle.pdf
A6-1 | Bottom stiffener angle, rear segment | angle | L2x2x1/4 ANGLE (2" x 2" x 1/4"), ASTM A36 | 10 | model | 200 [7-7/8"] | 0.94 | 9.43 | 2 | A | 28e51083 | pdf/A6-1_bottom-stiffener-angle-rear-segment.pdf
A6-2 | Bottom stiffener angle, middle segment | angle | L2x2x1/4 ANGLE (2" x 2" x 1/4"), ASTM A36 | 10 | model | 300 [11-13/16"] | 1.41 | 14.11 | 4 | A | c3f27e32 | pdf/A6-2_bottom-stiffener-angle-middle-segment.pdf
A6-3 | Bottom stiffener angle, front segment | angle | L2x2x1/4 ANGLE (2" x 2" x 1/4"), ASTM A36 | 10 | model | 250 [~9-13/16"] | 1.18 | 11.77 | 3 | A | f9ddbc56 | pdf/A6-3_bottom-stiffener-angle-front-segment.pdf
A7 | Platform side angle arm | angle | L2x2x1/4 ANGLE (2" x 2" x 1/4"), ASTM A36 | 2 | model | 247.6 [9-3/4"] | 1.14 | 2.28 | 4 | A | f7cf6c7b | pdf/A7_platform-side-angle-arm.pdf
A8 | Platform transverse angle | angle | L2x2x1/4 ANGLE (2" x 2" x 1/4"), ASTM A36 | 2 | model | 729.2 [~28-11/16"] | 3.44 | 6.87 | 3 | A | 4ed9ce9c | pdf/A8_platform-transverse-angle.pdf
A10 | Front stiffener outer angle | angle | L2x2x1/4 ANGLE (2" x 2" x 1/4"), ASTM A36 | 8 | model | 120.7 [4-3/4"] | 0.56 | 4.47 | 4 | A | a0c7d01c | pdf/A10_front-stiffener-outer-angle.pdf
T1 | Front frame cross tube | tube | HSS 6x2x1/4 RECT TUBE (2" x 6" x 1/4"), ASTM A500 | 1 | model | 1070.8 [~42-3/16"] | 20.18 | 20.18 | 12 | A | db041842 | pdf/T1_front-frame-cross-tube.pdf
T2 | Rear frame cross tube | tube | HSS 6x2x1/4 RECT TUBE (2" x 6" x 1/4"), ASTM A500 | 1 | model | 1070.8 [~42-3/16"] | 20.18 | 20.18 | 12 | A | db041842 | pdf/T2_rear-frame-cross-tube.pdf
T3 | Arm crossbeam tube | tube | HSS 6x2x1/4 RECT TUBE (2" x 6" x 1/4"), ASTM A500 | 1 | model | 849.2 [33-7/16"] | 16.58 | 16.58 | 4 | A | 0e838a26 | pdf/T3_arm-crossbeam-tube.pdf
T4 | Arm main tube | tube | HSS 6x2x1/4 RECT TUBE (2" x 6" x 1/4"), ASTM A500 | 2 | model | 1356.5 [~53-7/16"] | 24.54 | 49.08 | 8 | A | 125a5abd | pdf/T4_arm-main-tube.pdf
T6 | Arm pivot DOM tube | tube | DOM TUBE 2.000 OD x .250 WALL [50.8 x 6.35] | 2 | model | 120 [~4-3/4"] | 0.83 | 1.67 | 1 | A | 1518a5e5 | pdf/T6_arm-pivot-dom-tube.pdf
T7 | Wheel hub DOM tube | tube | DOM TUBE 2.000 OD [50.8], BORED TO THE ID SHOWN | 4 | model | 139.7 [5-1/2"] | 1.29 | 5.15 | 2 | A | ce69c997 | pdf/T7_wheel-hub-dom-tube.pdf
R1 | Lift cylinder base pin | bar | Ø1 [25.4] ROUND BAR, 4140 OR EQUIVALENT | 2 | model | 160 [6-5/16"] | 0.63 | 1.26 | 2 | A | ef5fe410 | pdf/R1_lift-cylinder-base-pin.pdf
R2 | Arm pivot pin | bar | Ø1-1/2 [38.1] ROUND BAR, 4140 OR EQUIVALENT | 2 | model | 226.4 [~8-15/16"] | 2.02 | 4.04 | 0 | A | 51085cad | pdf/R2_arm-pivot-pin.pdf
R3 | Clevis pin 3/4 | bar | Ø3/4 [19.05] ROUND BAR, 4140 OR EQUIVALENT | 4 | model | 106.2 [4-3/16"] | 0.23 | 0.94 | 2 | A | 66b1ddff | pdf/R3_clevis-pin-3-4.pdf
R4 | Bucket pivot pin | bar | Ø1 [25.4] ROUND BAR, 4140 OR EQUIVALENT | 2 | model | 106.2 [4-3/16"] | 0.42 | 0.83 | 2 | A | 72dd1313 | pdf/R4_bucket-pivot-pin.pdf
R5 | Platform pivot pin | bar | Ø1 [25.4] ROUND BAR, 4140 OR EQUIVALENT | 2 | model | 55.4 [2-3/16"] | 0.22 | 0.44 | 0 | A | 27f76c5e | pdf/R5_platform-pivot-pin.pdf
R6 | Wheel shaft | bar | Ø1-1/4 [31.75] ROUND SHAFTING | 4 | model | 474 [~18-11/16"] | 2.93 | 11.71 | 0 | A | fb8a4df3 | pdf/R6_wheel-shaft.pdf
U1 | Arm crossbeam cylinder lug | lug | HSS 3x3x1/4 SQUARE TUBE, ASTM A500 | 2 | model | 76.2 x 76.2 x 66.7 | 0.66 | 1.32 | 5 | A | 46fc755a | pdf/U1_arm-crossbeam-cylinder-lug.pdf
U2 | Bucket pivot lug | lug | HSS 3x3x1/4 SQUARE TUBE, ASTM A500 | 2 | model | 76.2 x 76.2 x 66.7 | 0.66 | 1.32 | 1 | A | e49d4fda | pdf/U2_bucket-pivot-lug.pdf
U3 | Bucket cylinder lug | lug | HSS 3x3x1/4 SQUARE TUBE, ASTM A500 | 2 | model | 76.2 x 76.2 x 66.7 | 0.68 | 1.36 | 1 | A | 8beef844 | pdf/U3_bucket-cylinder-lug.pdf
J1 | Tube drilling jig | printed | PLA OR PETG FILAMENT | 4 | manual | 177.7 x 101.5 x 76.1 | 0.64 | 2.57 | 2 | A | 998556df | pdf/J1_tube-drilling-jig.pdf
J2 | Pivot mount welding jig base | printed | PLA OR PETG FILAMENT | 1 | manual | 243.2 x 192.4 x 34.3 | 0.47 | 0.47 | 1 | A | 2458ae32 | pdf/J2_pivot-mount-welding-jig-base.pdf
J3 | Pivot mount welding jig ring | printed | PLA OR PETG FILAMENT | 2 | manual | 171.4 x 171.4 x 36.4 | 0.30 | 0.59 | 1 | A | b5d351d9 | pdf/J3_pivot-mount-welding-jig-ring.pdf
J4 | Pivot welding spacer jig | printed | PLA OR PETG FILAMENT | 2 | manual | 100 x 100 x 50.8 | 0.23 | 0.45 | 0 | A | 236bb234 | pdf/J4_pivot-welding-spacer-jig.pdf
J5 | Angle iron drill jig | printed | PLA OR PETG FILAMENT | 2 | manual | 100 x 54.8 x 54.8 | 0.05 | 0.10 | 2 | A | 8e3beaad | pdf/J5_angle-iron-drill-jig.pdf
J6 | Tube drill jig | printed | PLA OR PETG FILAMENT | 2 | manual | 160.4 x 58.8 x 50 | 0.10 | 0.20 | 0 | A | 9b6f9a77 | pdf/J6_tube-drill-jig.pdf
F1 | Hex nut 1-1/2-6 | fastener | HEX NUT 1-1/2-6 UNC-2B, GRADE 8, ASME B18.2.2 | 4 | model | 1-1/2-6 UNC | 0.42 | 1.69 | 0 | A | 5f99033d | pdf/F1_hex-nut-1-1-2-6.pdf
F2 | Platform lock pin 5/8 | fastener | HITCH / CLEVIS PIN Ø5/8 [15.875] x 1-5/16 USABLE, ZINC | 2 | model | Ø5/8 x 1-5/16 | 0.05 | 0.10 | 0 | A | dff4b9e8 | pdf/F2_platform-lock-pin-5-8.pdf
F3 | Hex bolt 1/2-13 | fastener | HEX BOLT 1/2-13 UNC-2A x L, SAE J429 GR 8, YELLOW ZINC, ASME B18.2.1 | 154 | holes | 1/2-13 x L (2 TO 6 IN) | 0.07 | 10.60 | 0 | A | 7c463b0b | pdf/F3_hex-bolt-1-2-13.pdf
F4 | Hex nut 1/2-13 | fastener | HEX NUT 1/2-13 UNC-2B, GRADE 8, YELLOW ZINC, ASME B18.2.2 | 154 | holes | 1/2-13 UNC | 0.02 | 2.46 | 0 | A | 7a01d011 | pdf/F4_hex-nut-1-2-13.pdf
F5 | Flat washer 1/2 SAE | fastener | FLAT WASHER 1/2 SAE (17/32 ID x 1-1/16 OD), HARDENED, ZINC | 308 | holes | 1/2 SAE | 0.01 | 2.50 | 0 | A | 2e20bb30 | pdf/F5_flat-washer-1-2-sae.pdf
F6 | Hex bolt 3/8-16 | fastener | HEX BOLT 3/8-16 UNC-2A x L, SAE J429 GR 8, YELLOW ZINC, ASME B18.2.1 | 170 | holes | 3/8-16 x L | 0.03 | 4.33 | 0 | A | 91df2721 | pdf/F6_hex-bolt-3-8-16.pdf
F7 | Hex nut 3/8-16 | fastener | HEX NUT 3/8-16 UNC-2B, GRADE 8, YELLOW ZINC, ASME B18.2.2 | 170 | holes | 3/8-16 UNC | 0.01 | 1.15 | 0 | A | 590452af | pdf/F7_hex-nut-3-8-16.pdf
F8 | Flat washer 3/8 SAE | fastener | FLAT WASHER 3/8 SAE (13/32 ID x 13/16 OD), HARDENED, ZINC | 340 | holes | 3/8 SAE | 0.00 | 1.11 | 0 | A | d7c9a218 | pdf/F8_flat-washer-3-8-sae.pdf
F9 | Hex bolt 1/4-20 | fastener | HEX BOLT 1/4-20 UNC-2A x 1, SAE J429 GR 5, ZINC, ASME B18.2.1 | 24 | manual | 1/4-20 x 1 | 0.01 | 0.23 | 0 | A | e9c19558 | pdf/F9_hex-bolt-1-4-20.pdf
F10 | Hex nut 1/4-20 | fastener | HEX NUT 1/4-20 UNC-2B, GRADE 5, ZINC, ASME B18.2.2 | 24 | manual | 1/4-20 UNC | 0.00 | 0.08 | 0 | A | 9d27122d | pdf/F10_hex-nut-1-4-20.pdf

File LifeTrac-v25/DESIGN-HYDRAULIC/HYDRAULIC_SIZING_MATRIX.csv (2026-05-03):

scenario_id | topology | pump_sku | pump_native_flange | pump_native_shaft | bell_housing_strategy | bell_housing_sku | bell_housing_cost_usd | coupling_sku | coupling_cost_usd | adapter_required | adapter_notes | stack_length_added_in | pump_section_a_cc | pump_section_b_cc | engine_rpm | vol_eff | mech_eff | section_a_gpm | section_b_gpm | total_gpm | track_motor_cipr | track_motor_cc | track_max_rpm | track_gpm_per_side | track_gpm_total | relief_psi | section_a_hp_at_relief | section_b_hp_at_relief | total_hp_at_relief | engine_hp_net | headroom_hp | notes
S1_single_11gpm_baseline | single-pump shared (current canonical BOM) | Haldex 1001601 or equiv 1.4 cipr SAE-A | SAE-A | 5/8 9T spline | off-the-shelf Vanguard-to-SAE-A kit | Bailey Hyd "Vanguard 18-23 HP to SAE-A pump mount kit" or Surplus Center equiv | 200 | L-jaw coupling included in kit (1-1/8 keyed engine + 5/8 9T spline pump hubs) | 0 | no | Native fit. Kit covers housing + coupling + spider. | 4.0 | 22.9 | n/a | 3600 | 0.85 | 0.88 | 11.0 | n/a | 11.0 | 12.0 | 196.6 | 106 | 5.5 | 11.0 | 3000 | 19.3 | n/a | 19.3 | 16 | -3.3 | Current §1 BOM. All 11 GPM through one EFC then split between 2 track valves + arm valves. No inherent L/R balance.
S2_tandem_8plus8_track_dedicated | tandem (track-dedicated section + arm section) | HY2-LN size 08+08 | SAE-A | 5/8 9T spline | off-the-shelf Vanguard-to-SAE-A kit | Bailey Hyd Vanguard-to-SAE-A kit | 200 | Included in kit | 0 | no | Native fit. Tandem pump = single overall mount; rear section bolts to front section per HY2-LN p11 procedure. | 4.5 | 8.2 | 8.2 | 3600 | 0.96 | 0.88 | 7.5 | 7.5 | 15.0 | 12.0 | 196.6 | 106 | 5.5 | 11.0 | 3000 | 13.1 | 13.1 | 26.2 | 16 | -10.2 | Each section feeds one track via own EFC. Inherent L/R match. ~2 GPM/side headroom for hill assist. Both sections at full pressure overloads engine = relief opens (normal).
S3_tandem_11plus8_asymmetric | tandem (front=arms big section + rear=tracks) | HY2-LN size 11+08 | SAE-A | 5/8 9T spline | off-the-shelf Vanguard-to-SAE-A kit | Bailey Hyd Vanguard-to-SAE-A kit | 200 | Included in kit | 0 | no | Native fit | 4.5 | 11.3 | 8.2 | 3600 | 0.96 | 0.88 | 10.3 | 7.5 | 17.8 | 12.0 | 196.6 | 106 | 3.75 | 7.5 | 3000 | 18.0 | 13.1 | 31.2 | 16 | -15.2 | Front 11cc handles arm/loader. Rear 8cc splits 7.5 GPM between both tracks via single EFC. Loses inherent L/R balance on rear; gains arm speed.
S4_tandem_14plus11_general | tandem (general 11cc base from earlier rec) | HY2-LN size 14+11 | SAE-A | 5/8 9T spline | off-the-shelf Vanguard-to-SAE-A kit | Bailey Hyd Vanguard-to-SAE-A kit | 200 | Included in kit | 0 | no | Native fit | 4.5 | 14.6 | 11.3 | 3600 | 0.96 | 0.88 | 13.3 | 10.3 | 23.6 | 12.0 | 196.6 | 106 | 5.5 | 11.0 | 2500 | 19.4 | 15.0 | 34.4 | 16 | -18.4 | Earlier conversational recommendation. Over-pumped for tracks; chronic relief = heat. Drop relief to 2500 PSI to keep within engine envelope at single-section full demand.
S5_single_LegacyOSE_22gpm | single-pump (legacy OSE high-flow build) | Haldex 1003114 2.8 cipr SAE-B | SAE-B | 7/8 13T spline | off-the-shelf Vanguard-23/Honda-GX630 to SAE-B kit | Bailey Hyd or Magnaloy SAE-B kit | 250 | L-jaw coupling with 1-1/8 keyed + 7/8 13T hubs | 0 | no | Off-the-shelf SAE-B kit available for larger Vanguard/Honda V-twins. | 4.5 | 45.9 | n/a | 3600 | 0.85 | 0.88 | 22.0 | n/a | 22.0 | 12.0 | 196.6 | 213 | 11.0 | 22.0 | 3000 | 38.5 | n/a | 38.5 | 30 | -8.5 | Reference build for ~30 HP engines (Vanguard 23/Honda GX630). Out of scope for current 18 HP plan but shown for comparison.
S6_tandem_HY1_microbuild | tandem (small experimental build) | HY1 075+075 | SAE-AA | 1/2 parallel keyed | custom adapter (no off-the-shelf SAE-AA kit for Vanguard 18 HP) | custom-machined SAE-AA face on Bailey/Magnaloy SAE-A housing or full custom plate | 300 | Custom L-jaw with 1-1/8 keyed + 1/2 keyed hubs (Lovejoy L-095) | 60 | yes | SAE-AA pumps are uncommon at this engine size - off-the-shelf kits jump from SAE-AA-on-small-engines (~5 HP) directly to SAE-A on Vanguard-class V-twins. Custom plate or re-machined SAE-A kit needed. | 5.0 | 7.5 | 7.5 | 3600 | 0.96 | 0.88 | 6.8 | 6.8 | 13.6 | 8.0 | 131.1 | 106 | 3.4 | 6.8 | 3000 | 11.9 | 11.9 | 23.8 | 16 | -7.8 | Bracket low end of HY family. Adapter cost erodes the pump price advantage. Confirm HY1 tandem availability with Hydreco - HY1 datasheet does not show explicit tandem kit.
S7_HY3_LN_22cc_singleSection | single (HY3-LN smallest as single pump) | HY3-LN size 22 (SAE-B) | SAE-B | 5/8 13T spline (SAE-B per HY3-LN p15) | off-the-shelf Vanguard-23/Honda-GX630 to SAE-B kit | Bailey Hyd or Magnaloy SAE-B kit | 250 | L-jaw with 1-1/8 keyed + 5/8 13T hubs (note: 5/8 13T is non-standard - confirm hub availability or step up to 7/8 13T via shaft sleeve) | 60 | no | SAE-B housing off-the-shelf. The HY3-LN 5/8 13T shaft is unusual; most SAE-B coupling hubs are 7/8 13T. Verify hub bore before ordering. | 4.5 | 22.0 | n/a | 3600 | 0.96 | 0.88 | 20.1 | n/a | 20.1 | 12.0 | 196.6 | 106 | 5.5 | 11.0 | 2500 | 29.3 | n/a | 29.3 | 16 | -13.3 | HY3-LN 22cc as single pump. Big jump from HY2 family. Need 23+ HP engine to fully utilize. Documented for upgrade path.
S8_HY3_LN_tandem_22plus22 | tandem (HY3-LN 22+22) | HY3-LN 22+22 (SAE-B) | SAE-B | 5/8 13T spline (SAE-B) | off-the-shelf Vanguard-23/Honda-GX630 to SAE-B kit | Bailey Hyd or Magnaloy SAE-B kit | 250 | Same caveat as S7 | 60 | no | Same shaft caveat as S7 | 5.0 | 22.0 | 22.0 | 3600 | 0.96 | 0.88 | 20.1 | 20.1 | 40.2 | 12.0 | 196.6 | 213 | 11.0 | 22.0 | 2000 | 46.9 | 46.9 | 93.8 | 30 | -63.8 | Future upgrade path with 30+ HP engine. Way over current envelope. Listed for completeness.
S9_HY2_LN_tandem_11plus11_track_match | tandem (matched per-track sections) | HY2-LN size 11+11 | SAE-A | 5/8 9T spline | off-the-shelf Vanguard-to-SAE-A kit | Bailey Hyd Vanguard-to-SAE-A kit | 200 | Included in kit | 0 | no | Native fit | 4.5 | 11.3 | 11.3 | 3600 | 0.96 | 0.88 | 10.3 | 10.3 | 20.6 | 12.0 | 196.6 | 106 | 5.5 | 11.0 | 3000 | 18.0 | 18.0 | 36.0 | 16 | -20.0 | Symmetric L/R tracks. ~5 GPM/side headroom over per-track demand. Single section (one valve switched) within engine envelope.
S10_HY1_HY2_mixed_NotSupported | (invalid - cross-family tandem - anti-pattern) | HY1 + HY2 stacked | mixed | mixed | custom intermediate (no factory or off-the-shelf solution) | fully custom intermediate plate machined locally | 400 | Custom couplings at both interfaces | 150 | yes | Hydreco datasheets only show HY3+HY3+HY2 (HY3-LN p5) or HY2+HY2 (HY2-LN p5) - cross-group HY1+HY2 tandem not factory supported, requires fully custom intermediate. NOT RECOMMENDED. | 2.0 | 7.5 | 8.2 | 3600 | 0.96 | 0.88 | 6.8 | 7.5 | 14.3 | 12.0 | 196.6 | 106 | 5.5 | 11.0 | 3000 | 12.0 | 13.1 | 25.1 | 16 | -9.1 | Listed as anti-pattern documenting why we should pick one group. The HY3-LN datasheet (p5) example HY3+HY3+HY2 is the only mixed config Hydreco documents.
target_skidsteer_perf | target spec (informational row) | N/A reference | n/a | n/a | n/a | n/a | 0 | n/a | 0 | n/a | n/a | 0 | n/a | n/a | n/a | n/a | n/a | n/a | n/a | 11.0 | n/a | n/a | n/a | 5.5 | 11.0 | 3000 | n/a | n/a | 16-18 | 16 | 0 | Target track speed ~3-4 mph at sprocket pitch dia ~10 in. Adjust track_motor_cipr based on final sprocket from DESIGN-STRUCTURAL.

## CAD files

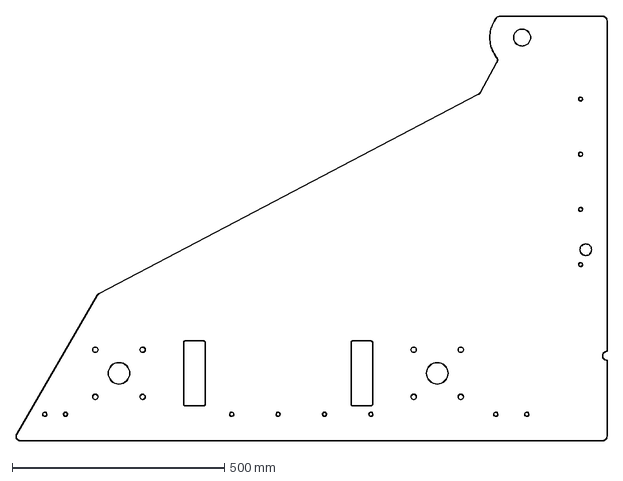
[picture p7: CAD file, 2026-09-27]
LifeTrac-v25/DESIGN-STRUCTURAL/drawings/generated/dxf/P1_side-panel-outer-left.dxf
1392.6 x 1000.0 mm

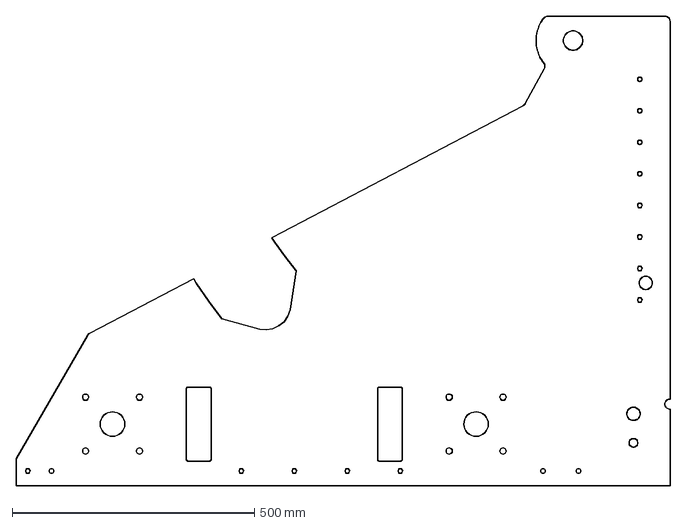
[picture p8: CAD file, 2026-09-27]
LifeTrac-v25/DESIGN-STRUCTURAL/drawings/generated/dxf/P3_side-panel-inner.dxf
1349.2 x 968.2 mm

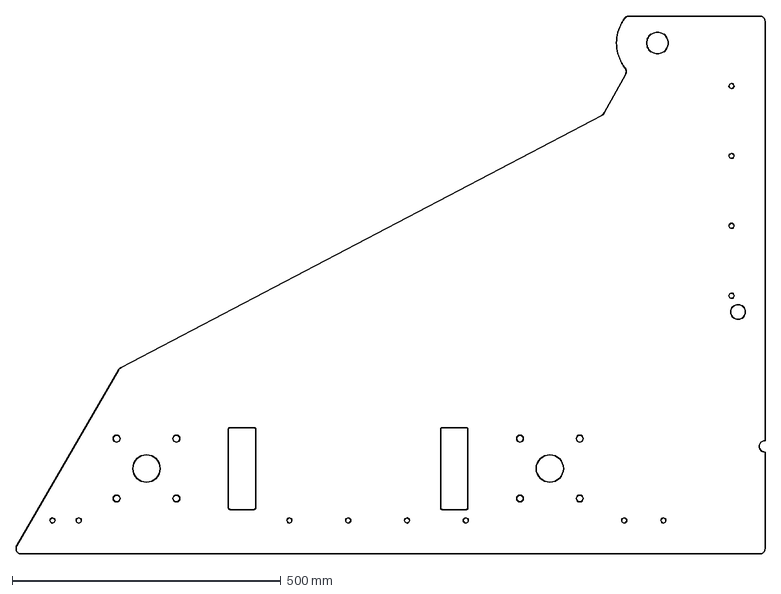
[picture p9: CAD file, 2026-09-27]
LifeTrac-v25/DESIGN-STRUCTURAL/drawings/generated/dxf/P2_side-panel-outer-right.dxf
1392.6 x 1000.0 mm

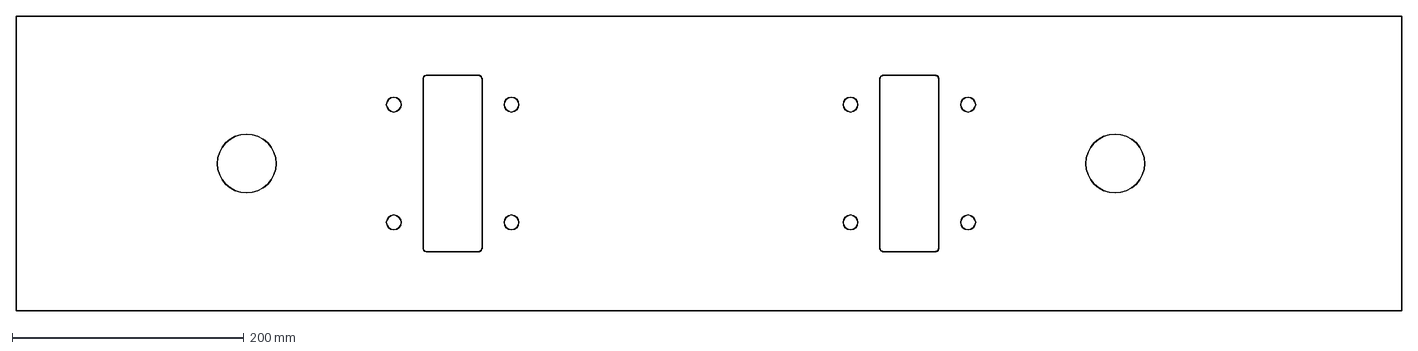
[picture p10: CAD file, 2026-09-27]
LifeTrac-v25/DESIGN-STRUCTURAL/drawings/generated/dxf/P8_motor-mounting-plate.dxf
1196.8 x 254.0 mm

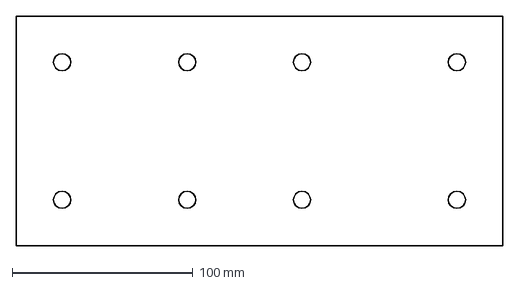
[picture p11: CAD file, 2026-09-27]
LifeTrac-v25/DESIGN-STRUCTURAL/drawings/generated/dxf/P6_front-stiffener-plate-outer.dxf
269.2 x 127.0 mm

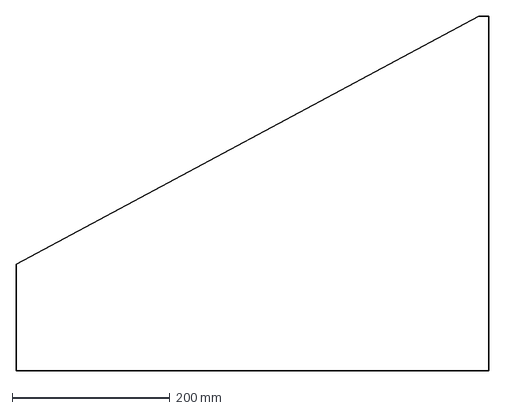
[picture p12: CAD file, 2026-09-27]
LifeTrac-v25/DESIGN-STRUCTURAL/drawings/generated/dxf/P14_bucket-side-plate.dxf
600.0 x 450.0 mm

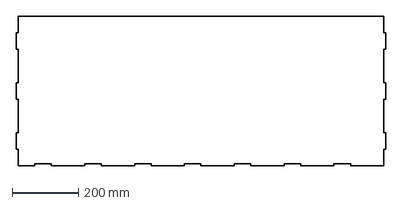
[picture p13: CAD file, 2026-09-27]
LifeTrac-v25/DESIGN-STRUCTURAL/drawings/generated/dxf/P12_bucket-back-plate.dxf
1112.7 x 450.0 mm

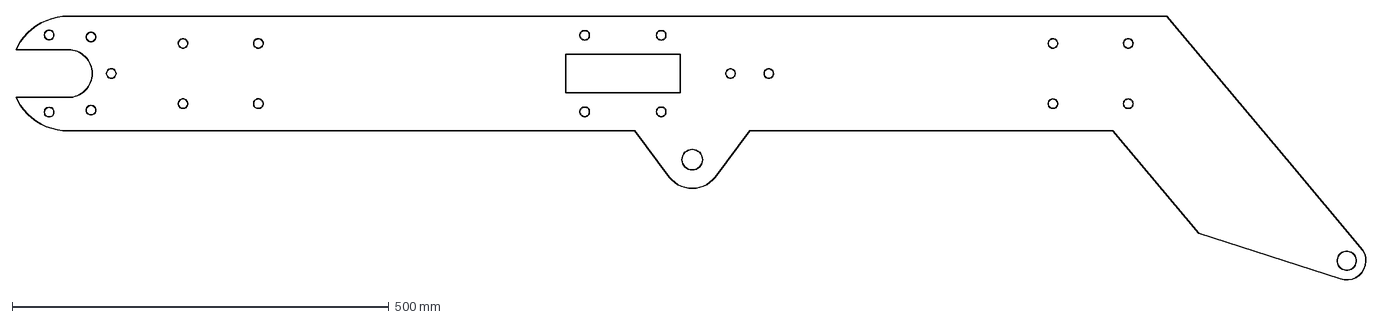
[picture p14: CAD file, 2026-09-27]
LifeTrac-v25/DESIGN-STRUCTURAL/drawings/generated/dxf/P9_arm-side-plate-inner.dxf
1792.0 x 350.1 mm

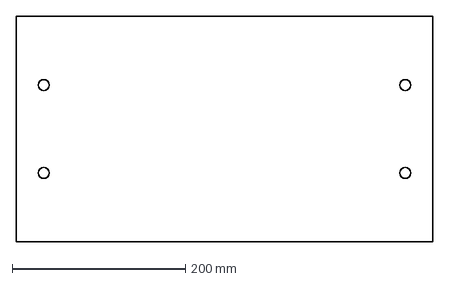
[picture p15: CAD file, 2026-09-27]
LifeTrac-v25/DESIGN-STRUCTURAL/drawings/generated/dxf/P5_front-stiffener-plate-centre.dxf
481.5 x 260.4 mm

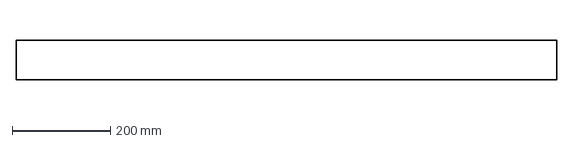
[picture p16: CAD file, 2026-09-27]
LifeTrac-v25/DESIGN-STRUCTURAL/drawings/generated/dxf/P19_bucket-cutting-edge.dxf
1100.0 x 80.0 mm

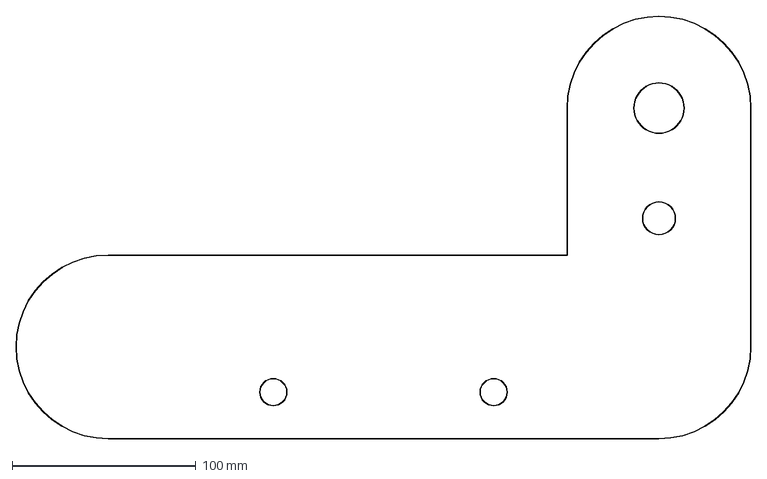
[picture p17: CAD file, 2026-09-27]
LifeTrac-v25/DESIGN-STRUCTURAL/drawings/generated/dxf/P16_platform-pivot-bracket.dxf
400.0 x 230.0 mm

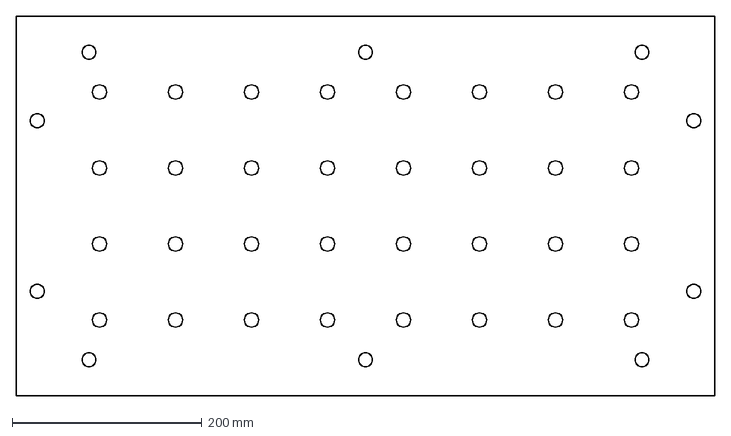
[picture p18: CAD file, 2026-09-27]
LifeTrac-v25/DESIGN-STRUCTURAL/drawings/generated/dxf/P15_platform-deck.dxf
735.5 x 400.0 mm

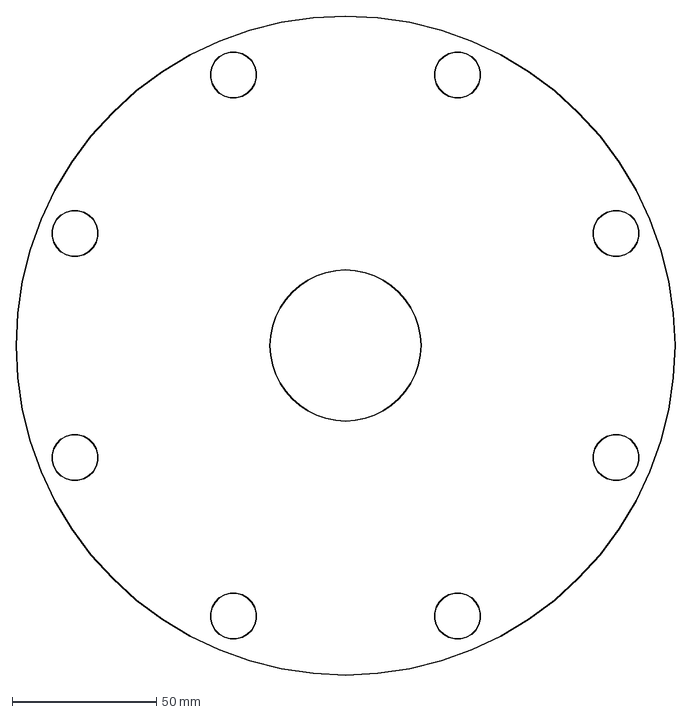
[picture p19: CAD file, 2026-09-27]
LifeTrac-v25/DESIGN-STRUCTURAL/drawings/generated/dxf/P17_wheel-hub-lug-plate.dxf
228.6 x 228.6 mm

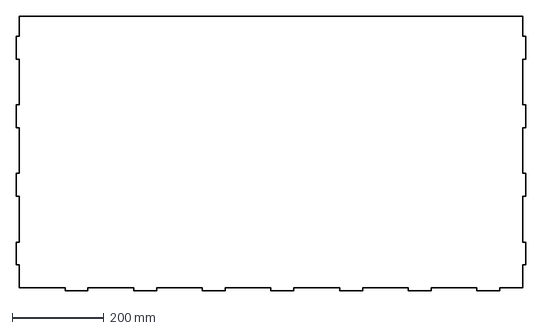
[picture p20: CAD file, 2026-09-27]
LifeTrac-v25/DESIGN-STRUCTURAL/drawings/generated/dxf/P13_bucket-bottom-plate.dxf
1112.7 x 600.0 mm

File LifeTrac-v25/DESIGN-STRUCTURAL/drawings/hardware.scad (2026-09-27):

// hardware.scad - reference models of purchased fasteners for the part drawings
//
// Nominal dimensions (inches) for inch-series hardware:
//   hex bolts / cap screws  ASME B18.2.1   (width across flats F, head height H)
//   hex nuts                ASME B18.2.2   (width across flats F, thickness T)
//   flat washers            SAE / USS pattern (ANSI B18.22.1 Type A)
// These are REFERENCE shapes for recognising and ordering hardware; buy to the
// callout on the drawing, not to these models.  Threads are shown simplified
// (ASME Y14.6): a single line marks where the thread starts.

IN = 25.4;

// [nominal dia, threads per inch, bolt F, bolt H, nut F, nut T]
HEX_TABLE = [
    [0.25,  20, 7/16,   5/32,  7/16,  7/32],
    [0.375, 16, 9/16,  15/64,  9/16, 21/64],
    [0.5,   13, 3/4,    5/16,  3/4,   7/16],
    [0.625, 11, 15/16, 25/64, 15/16, 35/64],
    [0.75,  10, 1.125, 15/32, 1.125, 41/64],
    [1.0,    8, 1.5,   39/64, 1.5,   55/64],
    [1.5,    6, 2.25,  15/16, 2.25,  1 + 9/32],
];

// [nominal dia, SAE ID, SAE OD, SAE t, USS ID, USS OD, USS t]
WASHER_TABLE = [
    [0.25,  9/32,  5/8,    0.065, 5/16,  3/4,   0.065],
    [0.375, 13/32, 13/16,  0.065, 7/16,  1,     0.083],
    [0.5,   17/32, 1.0625, 0.095, 9/16,  1.375, 0.109],
    [0.625, 21/32, 1.3125, 0.095, 11/16, 1.75,  0.134],
    [0.75,  13/16, 1.46875, 0.134, 13/16, 2,    0.148],
    [1.0,   1.0625, 2,     0.134, 1.0625, 2.5,  0.165],
];

function _row(table, d) = table[search([d], [for (r = table) r[0]])[0]];

module _hex(af, h) {
    cylinder(d = af / cos(30), h = h, $fn = 6);
}

// Hex bolt, head on the XY plane, shank along -Z.  length_in = under-head length.
module hex_bolt_ref(d_in, length_in) {
    r = _row(HEX_TABLE, d_in);
    d = d_in * IN;
    L = length_in * IN;
    thread = min(L, (length_in <= 6 ? 2 * d_in + 0.25 : 2 * d_in + 0.5) * IN);
    // Chamfered hex head (30 deg chamfer on the top corners).
    intersection() {
        _hex(r[2] * IN, r[3] * IN);
        cylinder(d1 = r[2] * IN / cos(30) + 2 * r[3] * IN, d2 = r[2] * IN * 0.95, h = r[3] * IN, $fn = 64);
    }
    // Plain shank, then the threaded length (shown a hair under major Ø so
    // the drawing gets a line where the thread starts).
    translate([0, 0, -(L - thread)]) cylinder(d = d, h = L - thread + 0.01, $fn = 48);
    translate([0, 0, -L]) {
        cylinder(d = d * 0.985, h = thread, $fn = 48);
    }
}

module hex_nut_ref(d_in) {
    r = _row(HEX_TABLE, d_in);
    difference() {
        intersection() {
            _hex(r[4] * IN, r[5] * IN);
            // Double-chamfered nut faces.
            union() {
                cylinder(d1 = r[4] * IN * 0.95, d2 = r[4] * IN / cos(30) + r[5] * IN, h = r[5] * IN / 2, $fn = 64);
                translate([0, 0, r[5] * IN / 2])
                cylinder(d1 = r[4] * IN / cos(30) + r[5] * IN, d2 = r[4] * IN * 0.95, h = r[5] * IN / 2, $fn = 64);
            }
        }
        translate([0, 0, -1]) cylinder(d = d_in * IN, h = r[5] * IN + 2, $fn = 48);
    }
}

module flat_washer_ref(d_in, pattern = "SAE") {
    r = _row(WASHER_TABLE, d_in);
    k = pattern == "USS" ? 4 : 1;
    difference() {
        cylinder(d = r[k + 1] * IN, h = r[k + 2] * IN, $fn = 96);
        translate([0, 0, -1]) cylinder(d = r[k] * IN, h = r[k + 2] * IN + 2, $fn = 64);
    }
}

// Plain pin (round bar cut to length), axis along X.
module pin_ref(d_mm, length_mm) {
    rotate([0, 90, 0]) cylinder(d = d_mm, h = length_mm, $fn = 64);
}

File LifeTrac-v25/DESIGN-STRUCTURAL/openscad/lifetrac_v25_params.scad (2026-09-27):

// lifetrac_v25_params.scad
// Essential parameters for LifeTrac v25 individual parts
// This file contains only the constants needed for part design
// Full assembly uses lifetrac_v25.scad

// -----------------------------------------------------------------------------
// Compatibility helper
// OpenSCAD throws warnings when the BOSL2 helper `parent_modules()` is missing.
// We provide a stub that returns an empty list so part files can run cleanly
// when opened directly without pulling in BOSL2.
function parent_modules() = is_undef($parent_modules) ? [] : $parent_modules;

// =============================================================================
// MATERIAL CONSTANTS
// =============================================================================

PLATE_1_4_INCH = 6.35;   // 1/4" = 6.35mm
PLATE_1_2_INCH = 12.7;   // 1/2" = 12.7mm
PLATE_3_4_INCH = 19.05;  // 3/4" = 19.05mm
TUBE_3X3_1_4 = [76.2, 6.35];    // 3"x3" x 1/4" wall
TUBE_4X4_1_4 = [101.6, 6.35];   // 4"x4" x 1/4" wall (OSE standard)
TUBE_2X2_1_4 = [50.8, 6.35];    // 2"x2" x 1/4" wall
TUBE_2X4_1_4 = [50.8, 101.6, 6.35]; // 2"x4" rectangular

// Angle iron sizes [leg_size, thickness]
ANGLE_2X2_1_4 = [50.8, 6.35];   // 2"x2" x 1/4" angle iron
ANGLE_3X3_1_4 = [76.2, 6.35];   // 3"x3" x 1/4" angle iron
ANGLE_4X4_1_4 = [101.6, 6.35];  // 4"x4" x 1/4" angle iron

// Bolt/pin diameters
PIVOT_PIN_DIA = 38.1;    // 1.5" pivot pin
BUCKET_PIVOT_PIN_DIA = 25.4; // 1" bucket pivot pin
BOLT_DIA_1_2 = 12.7;     // 1/2" bolt
BOLT_DIA_3_4 = 19.05;    // 3/4" bolt
BOLT_DIA_1 = 25.4;       // 1" bolt

// =============================================================================
// MACHINE DIMENSIONS
// =============================================================================

// Target size: between Toro Dingo (915mm wide) and Bobcat (1830mm wide)
MACHINE_WIDTH = 1200;    // Overall width
MACHINE_LENGTH = 1800;   // Overall length
MACHINE_HEIGHT = 1000;   // Height to top of frame
WHEEL_BASE = 1400;       // Distance between front and rear axles
TRACK_WIDTH = 900;       // Distance between centerlines of left/right side panels

// Side panel sandwich configuration
SANDWICH_SPACING = 120;  // Gap between inner and outer panels (for arm pivot)
PANEL_THICKNESS = PLATE_1_2_INCH;

// Wheel dimensions
WHEEL_DIAMETER = 500;    // 500mm diameter wheels
WHEEL_WIDTH = 200;       // 200mm wide wheels
WHEEL_CLEARANCE = 50;    // Clearance between wheel and outer panel

// Ground clearance - bottom of frame above ground
GROUND_CLEARANCE = 150;  // 150mm ground clearance under frame
WHEEL_RADIUS = WHEEL_DIAMETER / 2;

// Frame sits with bottom at GROUND_CLEARANCE height
FRAME_Z_OFFSET = GROUND_CLEARANCE;

// Calculate wheel X offset - wheels positioned outside the outer panels
WHEEL_X_OFFSET = TRACK_WIDTH/2 + SANDWICH_SPACING/2 + PANEL_THICKNESS + WHEEL_WIDTH/2 + WHEEL_CLEARANCE;

// =============================================================================
// BUCKET DIMENSIONS (Moved Up for Geometry Solver and Reach Calculation)
// =============================================================================

BOBCAT_QA_WIDTH = 1168;           // 46" standard width
BOBCAT_QA_HEIGHT = 457;           // 18" plate height
BOBCAT_QA_PIN_DIA = 25.4;         // 1" locking pin

BUCKET_WIDTH = 1100;              // Slightly narrower than QA plate
BUCKET_DEPTH = 600;
BUCKET_HEIGHT = 450;

// Design constraints
BUCKET_GROUND_CLEARANCE = 0; // Bucket flush with ground (Z=0)
BUCKET_FRONT_CLEARANCE_BASE = 0; // Base forward clearance (mm)
BUCKET_FRONT_CLEARANCE_ADJUST = 1.5 * 25.4; // Forward tweak (+) in mm
BUCKET_FRONT_CLEARANCE = BUCKET_FRONT_CLEARANCE_BASE + BUCKET_FRONT_CLEARANCE_ADJUST;

// Bucket Pivot Height Configuration
// We align the pivot to be at 1/5 of the bucket height (standard stability position)
BUCKET_PIVOT_HEIGHT_FROM_BOTTOM = BUCKET_HEIGHT / 5; // 450 / 5 = 90mm

// BUCKET_PIVOT_Y_OFFSET: Calculated after arm geometry to align bucket lug pin with arm tip pin hole
// See calculation below ARM_TIP_X/ARM_TIP_Z definitions

// =============================================================================
// LOADER ARM DIMENSIONS
// =============================================================================

// Design constraints (Moved above)

/* 
// Moved logic further down to BUCKET section for consistency
BUCKET_PIVOT_HEIGHT_BASE = 200; // Nominal height of pivot from bottom of bucket
BUCKET_PIVOT_HEIGHT_ADJUST = -5 * 25.4; // Lower lug (~5")
BUCKET_PIVOT_HEIGHT_FROM_BOTTOM = BUCKET_PIVOT_HEIGHT_BASE + BUCKET_PIVOT_HEIGHT_ADJUST;
*/

// Arm pivot point (at top rear of side panels - tall end)
ARM_PIVOT_Y = 200;  // Near rear of machine, between sandwich plates  
ARM_PIVOT_Z_HEIGHT = MACHINE_HEIGHT - 50;  // Height above frame bottom
ARM_PIVOT_Z = FRAME_Z_OFFSET + ARM_PIVOT_Z_HEIGHT;  // Absolute Z position

// Calculate required arm length
MIN_HORIZONTAL_REACH = WHEEL_BASE + BUCKET_FRONT_CLEARANCE - ARM_PIVOT_Y;
ARM_LENGTH = ceil(sqrt(pow(ARM_PIVOT_Z, 2) + pow(MIN_HORIZONTAL_REACH, 2)));
ARM_GROUND_ANGLE = asin(ARM_PIVOT_Z / ARM_LENGTH);  // Angle below horizontal (degrees)

ARM_TUBE_SIZE = TUBE_3X3_1_4;         // 3"x3" arm tubing
ARM_SPACING = TRACK_WIDTH;            // Distance between arm centerlines

// =============================================================================
// LOADER ARM V2 PARAMETERS (L-SHAPE)
// =============================================================================

TUBE_2X6_1_4 = [50.8, 152.4, 6.35]; // 2"x6" rectangular tubing
// ARM_ANGLE = 130; // Main arm angle in degrees (Sharpened to 130 as requested) - CALCULATED BELOW
ARM_PLATE_THICKNESS = PLATE_1_4_INCH;
DOM_PIPE_OD = 50.8; // Approximate OD for pivot holder (2" DOM)
DOM_PIPE_ID = 38.1; // ID matching 1.5" pivot pin
JIG_WALL_THICKNESS = 4; // Standard wall thickness for 3D printed jigs
JIG_CLEARANCE = 0.5; // Clearance for fit

// Tube bolt hole positioning
TUBE_BOLT_INSET = 50.8;                 // 2" distance from tube edge to NEAREST bolt

// =============================================================================
// PIVOT MOUNT ASSEMBLY PARAMETERS
// =============================================================================
// Replaceable pivot mount assembly that slides into arm from bottom
// Consists of 2 circular plates welded to a DOM tube section

PIVOT_MOUNT_PLATE_DIA = 152.4;          // 6" = 152.4mm diameter circular plates
PIVOT_MOUNT_PLATE_THICK = PLATE_1_4_INCH; // 1/4" plate thickness
PIVOT_MOUNT_BOLT_COUNT = 5;             // Number of bolts per plate
PIVOT_MOUNT_BOLT_DIA = BOLT_DIA_1_2;    // 1/2" mounting bolts
PIVOT_MOUNT_BOLT_CIRCLE_DIA = 114.3;    // 4.5" bolt circle diameter

// Slot position and NON-UNIFORM bolt spacing
// Slot is at back (180°) for DOM to slide in from rear of arm
// In arm plate coordinates: 0°=right (toward arm tip), 90°=up, 180°=left (back), 270°=down
PIVOT_MOUNT_SLOT_ANGLE = 180;           // Angle where DOM slot is located (back of arm)
PIVOT_MOUNT_BOLT_SLOT_CLEARANCE = 127;  // 5" total arc clearance across slot for bolts (2.5" each side)

// Calculate slot gap angle from clearance distance
// Arc length = radius × angle(radians), so angle(deg) = clearance / radius × 180/π
_pivot_bolt_radius = PIVOT_MOUNT_BOLT_CIRCLE_DIA / 2;  // 57.15mm
PIVOT_MOUNT_SLOT_GAP_ANGLE = PIVOT_MOUNT_BOLT_SLOT_CLEARANCE / _pivot_bolt_radius * 180 / PI;  // ~50.9° for 2"

// Non-uniform spacing: slot gap is larger, remaining bolts are closer
// With N bolts: 1 slot gap + (N-1) regular gaps = 360°
// regular_gap = (360° - slot_gap) / (N-1)
_pivot_regular_gap = (360 - PIVOT_MOUNT_SLOT_GAP_ANGLE) / (PIVOT_MOUNT_BOLT_COUNT - 1);

// Calculate bolt angles array
// Two bolts flank the slot at: slot_angle ± half_slot_gap
// Bolt A (CCW from slot): slot_angle - half_gap = 270° - 25.45° ≈ 244.55°
// Bolt B (CW from slot):  slot_angle + half_gap = 270° + 25.45° ≈ 295.45°
// Remaining bolts fill in with regular spacing going CCW from Bolt B
_half_slot_gap = PIVOT_MOUNT_SLOT_GAP_ANGLE / 2;
_bolt_A_angle = PIVOT_MOUNT_SLOT_ANGLE - _half_slot_gap;  // ~244.55° (lower-left, just before slot)
_bolt_B_angle = PIVOT_MOUNT_SLOT_ANGLE + _half_slot_gap;  // ~295.45° (lower-right, just after slot)

// Build array: start at Bolt B (after slot), go CCW around, end at Bolt A (before slot)
PIVOT_MOUNT_BOLT_ANGLES = [
    for (i = [0:PIVOT_MOUNT_BOLT_COUNT-1])
        _bolt_B_angle + i * _pivot_regular_gap
];
// Result for 5 bolts: [295.45, 372.7, 449.9, 527.2, 604.4] = [295.45°, 12.7°, 89.9°, 167.2°, 244.4°]
// Bolt 0 (295.45°) and Bolt 4 (244.4°) flank the 270° slot
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

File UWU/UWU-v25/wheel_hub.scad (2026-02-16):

// wheel_hub.scad
// UWU Wheel Hub Assembly
// Open Source Ecology - LifeTrac v25 / UWU-v25
//
// Wheel hub that mounts on the UWU shaft and accepts
// standard Bobcat skid-steer wheels (P/N 7232567, 8-lug on 8" BCD).
//
// Two hub styles available (set _hub_style):
//   "DIY" - Fabricated from DOM tube + triangular gussets + lug plate
//   "QD"  - QD weld-on hub (SH series) welded to lug plate + QD bushing
//
// DIY Construction:
//   1. DOM (Drawn Over Mandrel) tube - slides over the 1.25" shaft
//   2. Triangular plate steel gussets - welded to DOM and lug plate
//   3. Circular lug bolt plate - 8 holes matching Bobcat pattern
//   4. Cross-drilled hole through DOM + shaft for retention bolt
//
// QD Construction:
//   1. QD weld-on hub (SH series, Martin/McMaster) - welded to lug plate
//   2. QD tapered bushing - clamps onto shaft via cap screws
//   3. Circular lug bolt plate - 8 holes matching Bobcat pattern
//
// Units: mm (all dimensions converted from inches)

$fn = 48;
inch = 25.4;

// =============================================================================
// PARAMETERS (defaults match lifetrac_v25_params.scad)
// =============================================================================

// DOM tube
_hub_shaft_diam = 31.75;         // 1.25"
_hub_dom_od     = 50.8;          // 2.00" OD
_hub_dom_wall   = 6.35;          // 0.25" wall
_hub_dom_id     = _hub_shaft_diam + 0.79375;  // Shaft OD + 1/32" clearance
_hub_dom_length = 101.6;         // 4.00" long

// Cross-drill retention bolt
_hub_cross_bolt_diam = 12.7;     // 1/2" bolt
_hub_cross_bolt_pos  = _hub_dom_length / 2;  // centered along DOM

// Lug bolt plate (circular)
_hub_plate_diam      = 228.6;    // 9.00" diameter
_hub_plate_thickness = 12.7;     // 1/2" plate

// Bobcat bolt pattern
_bobcat_lug_count = 8;
_bobcat_bcd       = 203.2;       // 8.00" bolt circle
_bobcat_lug_hole  = 15.875;      // 5/8" clearance holes
_bobcat_center_bore = 76.2;      // 3.00" center bore (rim side)
// Hub plate center bore: DOM OD + 1/16" clearance
_hub_plate_center_bore = _hub_dom_od + 1.5875;

// Gusset plates
_hub_gusset_count     = 4;
_hub_gusset_thickness = 6.35;    // 1/4" plate
_hub_gusset_height    = _hub_dom_length * 0.85;
// Offset 22.5° so gussets sit between the 8 lug bolt holes
_hub_gusset_angle_offset = 22.5;

// =============================================================================
// QD WELD-ON HUB PARAMETERS (SH series, 1-1/4" bore)
// =============================================================================
// Martin Sprocket / McMaster SH QD bushing + weld-on hub
_qd_bore            = _hub_shaft_diam;  // 31.75mm (1.250")
_qd_barrel_od       = 66.04;     // 2.600" (large end of taper)
_qd_flange_od       = 76.2;      // 3.000"
_qd_overall_length  = 33.34;     // 1.3125" (1-5/16")
_qd_flange_thick    = 7.94;      // 0.3125" (5/16")
_qd_barrel_length   = 25.4;      // 1.000"
_qd_bolt_circle     = 57.15;     // 2.250" bolt circle
_qd_num_bolts       = 2;         // 2x 5/16"-18 cap screws
_qd_bolt_diam       = 7.94;      // 5/16"
_qd_hub_flange_od   = 76.2;      // 3.000" weld-on hub flange
_qd_hub_width       = 20.64;     // 0.8125" (13/16") weld-on hub width

// Hub style toggle: "DIY" or "QD"
_hub_style = "DIY";

// =============================================================================
// DOM TUBE MODULE
// =============================================================================
// Drawn Over Mandrel steel tube that slides over the shaft.
// Cross-drilled for retention bolt.

module hub_dom_tube(
    od     = _hub_dom_od,
    id     = _hub_dom_id,
    length = _hub_dom_length,
    cross_bolt_diam = _hub_cross_bolt_diam,
    cross_bolt_pos  = _hub_cross_bolt_pos
) {
    color("DimGray")
    difference() {
        // Tube body
        cylinder(d=od, h=length, center=false);

        // Bore
        translate([0, 0, -1])
        cylinder(d=id, h=length + 2, center=false);

        // Cross-drill hole (perpendicular, centered between gussets)
        translate([0, 0, cross_bolt_pos])
        rotate([0, 0, 67.5])
        rotate([0, 90, 0])
        cylinder(d=cross_bolt_diam, h=od + 2, center=true);
    }
}

// =============================================================================
// LUG BOLT PLATE MODULE
// =============================================================================
// Circular plate with Bobcat 8-lug pattern.
// Welded to the gussets/DOM tube at one end.

module hub_lug_plate(
    plate_diam     = _hub_plate_diam,
    plate_thick    = _hub_plate_thickness,
    lug_count      = _bobcat_lug_count,
    bcd            = _bobcat_bcd,
    lug_hole_diam  = _bobcat_lug_hole,
    center_bore    = _hub_plate_center_bore
) {
    color("Silver")
    difference() {
        // Main circular plate
        cylinder(d=plate_diam, h=plate_thick, center=false);

        // Center bore
        translate([0, 0, -1])
        cylinder(d=center_bore, h=plate_thick + 2, center=false);

        // Lug bolt holes (evenly spaced on BCD)
        for (i = [0 : lug_count - 1]) {
            rotate([0, 0, i * (360 / lug_count)])
            translate([bcd / 2, 0, -1])
            cylinder(d=lug_hole_diam, h=plate_thick + 2, $fn=24);
        }
    }
}

// =============================================================================
// TRIANGULAR GUSSET PLATE MODULE
// =============================================================================
// Single triangular gusset that connects the DOM tube to the lug plate.
// Radiates outward from the DOM OD to the lug plate edge.

module hub_gusset(
    dom_od         = _hub_dom_od,
    plate_diam     = _hub_plate_diam,
    gusset_height  = _hub_gusset_height,
    gusset_thick   = _hub_gusset_thickness
) {
    // Triangle profile:
    //   - Inner edge at DOM tube OD/2
    //   - Outer edge at lug plate radius
    //   - Height along the Z axis (DOM axis)
    inner_r = dom_od / 2;
    outer_r = plate_diam / 2 - 5;  // Slight inset from plate edge
    radial_length = outer_r - inner_r;

    color("DarkGray")
    translate([inner_r, 0, 0])
    rotate([-90, 0, 0])
    linear_extrude(height=gusset_thick, center=true)
    // Triangle in radial-axial plane: base at plate, apex up DOM
    polygon(points=[
        [0, 0],                        // Inner at plate level
        [radial_length, 0],            // Outer at plate level
        [0, gusset_height]             // Inner up DOM axis
    ]);
}

// =============================================================================
// QD TAPERED BUSHING MODULE (SH series)
// =============================================================================
// Standard SH QD bushing: tapered split sleeve that clamps onto the shaft.
// The bushing sits inside the weld-on hub's tapered bore.

module qd_bushing(
    bore         = _qd_bore,
    barrel_od    = _qd_barrel_od,
    flange_od    = _qd_flange_od,
    overall_len  = _qd_overall_length,
    flange_thick = _qd_flange_thick,
    barrel_len   = _qd_barrel_length,
    bolt_circle  = _qd_bolt_circle,
    num_bolts    = _qd_num_bolts,
    bolt_diam    = _qd_bolt_diam
) {
    color("DimGray")
    difference() {
        union() {
            // Tapered barrel
            cylinder(d1=barrel_od, d2=barrel_od * 0.95, h=barrel_len, $fn=48);
            // Flange at top
            translate([0, 0, barrel_len])
            cylinder(d=flange_od, h=flange_thick, $fn=48);
        }
        // Bore
        translate([0, 0, -1])
        cylinder(d=bore, h=overall_len + 2, $fn=48);
        // Cap screw holes in flange
        for (i = [0 : num_bolts - 1]) {
            rotate([0, 0, i * (360 / num_bolts)])
            translate([bolt_circle / 2, 0, barrel_len - 1])
            cylinder(d=bolt_diam, h=flange_thick + 2, $fn=16);
        }
    }
}

// =============================================================================
// QD WELD-ON HUB MODULE (SH series)
// =============================================================================
// Steel hub with SH tapered bore, flat flange face for welding to lug plate.
// Bushing inserts from the inboard side.

module qd_weld_on_hub(
    hub_flange_od = _qd_hub_flange_od,
    hub_width     = _qd_hub_width,
    barrel_od     = _qd_barrel_od,
    bolt_circle   = _qd_bolt_circle,
    num_bolts     = _qd_num_bolts,
    bolt_diam     = _qd_bolt_diam
) {
    color("SlateGray")
    difference() {
        // Main body: cylindrical hub
        cylinder(d=hub_flange_od, h=hub_width, $fn=48);
        // Tapered bore (matching SH bushing taper)
        translate([0, 0, -1])
        cylinder(d1=barrel_od, d2=barrel_od * 0.95, h=hub_width + 2, $fn=48);
        // Cap screw holes (tapped, through hub body)
        for (i = [0 : num_bolts - 1]) {
            rotate([0, 0, i * (360 / num_bolts)])
            translate([bolt_circle / 2, 0, -1])
            cylinder(d=bolt_diam, h=hub_width + 2, $fn=16);
        }
    }
}
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

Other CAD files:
LifeTrac-v25/DESIGN-STRUCTURAL/drawings/generated/dxf/P4_back-stiffener-plate.dxf
LifeTrac-v25/DESIGN-STRUCTURAL/drawings/generated/dxf/P11_arm-pivot-mount-plate.dxf
LifeTrac-v25/DESIGN-STRUCTURAL/drawings/generated/dxf/P7_bottom-stiffener-plate.dxf
LifeTrac-v25/DESIGN-STRUCTURAL/drawings/generated/dxf/P10_arm-side-plate-outer.dxf
LifeTrac-v25/DESIGN-STRUCTURAL/openscad/modules/loader_arm_v2.scad
LifeTrac-v25/DESIGN-STRUCTURAL/drawings/generated/dxf/P18_wheel-hub-gusset.dxf
LifeTrac-v25/DESIGN-STRUCTURAL/openscad/3d_printed_bolt_hole_cutting_jigs/angle_iron_drill_jig.scad
LifeTrac-v25/DESIGN-STRUCTURAL/openscad/3d_printed_bolt_hole_cutting_jigs/tube_drill_jig.scad
LifeTrac-v25/DESIGN-STRUCTURAL/openscad/3d_printed_welding_jigs/pivot_mount_welding_jig.scad
LifeTrac-v25/DESIGN-STRUCTURAL/openscad/3d_printed_welding_jigs/pivot_welding_jig.scad
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

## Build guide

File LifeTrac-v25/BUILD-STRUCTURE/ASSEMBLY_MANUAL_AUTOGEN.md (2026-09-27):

# Auto-generating a LEGO / IKEA-style assembly manual for LifeTrac v25

**Status:** design proposal. Phase 0 (the editable step list) is implemented;
the rest is a plan.

**Related:**
* [`assembly_sequence.yaml`](assembly_sequence.yaml): the editable step list.
* [`ASSEMBLY_SEQUENCE.md`](ASSEMBLY_SEQUENCE.md): the generated numbered list.
* [`../DESIGN-STRUCTURAL/drawings/`](../DESIGN-STRUCTURAL/drawings/): part
  drawings, part numbers and model-counted quantities.

## 1. What we want

A picture-first build book that anyone with a welder and a drill press can
follow. It should need almost no words and never go out of date with the model.
Every step page shows:

```
+--------------------------------------------------------------+
|  12                                   [x2]   [2-person lift] |
|  +-------------------+                                       |
|  | [T1] x1  [A4] x8  |       machine so far: light grey      |
|  | [F3] x16 (1:1)    |       new parts: bold, coloured       |
|  +-------------------+       arrow + dashed path showing     |
|                              where the new parts go          |
|  [tools: 3/4" wrench, J1 jig]                  (rotate icon) |
+--------------------------------------------------------------+
```

* **A big step number.** It is derived from the order of the steps; nobody
  types it.
* **A parts callout box** (LEGO calls it the PLI). It shows a thumbnail of each
  part added in the step, with its part number and count. Bolts, nuts and washers
  are drawn **at 1:1 scale** so they can be matched by laying them on the page,
  as IKEA does.
* **The assembly so far** in light grey. The **new parts** are bold and coloured,
  with an arrow and a dashed guide line from where they start to where they go.
* **Sub-assemblies** built off the machine, drawn in a framed callout. A `x2`
  badge shows when two are needed (left and right arms, four wheel hubs).
* **Icons:** tools and jigs; a two-person/hoist icon when a part is heavy (the
  outer side panel is 82 kg, calculated on its drawing); a "turn the model" icon
  when the viewpoint swings round.

## 2. Why LEGO and IKEA instructions work, and what we borrow

* **Research basis.** Agrawala et al., *Designing Effective Step-By-Step
  Assembly Instructions* (SIGGRAPH 2003), drew their design principles from
  cognitive-psychology studies of how people understand and communicate assembly.
  They then built a system that generates instructions automatically from a model
  and an assembly sequence, drawing on earlier robotics work on assembly
  planning. The principles we adopt:
  * Add parts in small, meaningful groups, and add symmetric or identical parts in
    the same step.
  * Keep every new part and its attachment point visible.
  * Keep the viewpoint stable and only change it when the work demands it.
  * Build hierarchically, using sub-assemblies.
  * Show both what the result looks like (a structural diagram) and how to get
    there (an action diagram, with arrows and guide lines).
* **LEGO / LDraw precedent.** The open-source
  [LPub3D](https://trevorsandy.github.io/lpub3d/) generates LEGO-style
  instructions from an LDraw model plus step markers. It produces per-step parts
  lists, automatic sub-model callouts and a bill of materials. That is the same
  shape as this proposal: *model + ordered step list → rendered pages*.
* **IKEA.** Its manuals are wordless and draw hardware at 1:1. They use tool
  icons, "two people" icons and do/don't panels. For a steel tractor, the 1:1
  hardware and two-person/hoist icons matter most.

## 3. What already exists

| Piece | Where | Used by the manual for |
|---|---|---|
| Part numbers, names, stock | `DESIGN-STRUCTURAL/drawings/parts_manifest.yaml` (a new part is drawn and in `generated/bom.csv` before it has an entry) | Callout labels, links to drawings |
| Quantities counted from the model | `echo(BOM_PART = …)` markers → `generated/bom.csv` | Checking every part is placed exactly once |
| Per-part isometric renders | The part-drawing generator (`partdrawings/`) | Callout-box thumbnails |
| Hidden-line line-art engine | `partdrawings/hlr.py` | IKEA-style vector step drawings |
| Part mass | Title blocks / `bom.csv` | Two-person/hoist icons |
| **Editable ordered step list** | `assembly_sequence.yaml` | Everything below |
| Step list checker + numbered list | `assembly_sequence.py` → `ASSEMBLY_SEQUENCE.md` | Kept green by CI |

### The numbered list: which part goes on next

[`assembly_sequence.yaml`](assembly_sequence.yaml) is the single source of truth:

```yaml
phases:
  - id: frame
    title: Base frame
    steps:
      - id: cross-tubes                       # stable id - never renumbered or reused
        title: Slide the front and rear cross tubes through the panel windows and bolt on the tube angles
        after: [inner-panels, motor-plates-install]
        add:
          - {part: T1, qty: 1}
          - {part: T2, qty: 1}
          - {part: A4, qty: 16}
        tools: [J1]
        status: draft                          # draft | checked | verified
```

* **Numbering is derived, never stored.** Step numbers come from the order of
  the list. Inserting, moving or deleting a step renumbers everything after it.
* **Every step has a permanent `id`.** Issues, photos, comments and the future
  manual refer to that. When a builder finds that step 14 must come before step
  12, someone moves one block of YAML in a pull request. The ids stay the same,
  so nothing that points at them breaks.
* **The checker runs in CI.** It uses the same workflow as the part drawings.
  * It **fails** on an unknown part number, on a part used more times than the
    model has it, on a duplicate id, on an `after`/`uses` that points forward,
    or on a sub-assembly installed twice.
  * It **warns** about parts no step places. That becomes an error once the file
    is marked `complete: true`.
  * It regenerates [`ASSEMBLY_SEQUENCE.md`](ASSEMBLY_SEQUENCE.md). That file is
    the human-readable numbered list, with a running "placed so far / per
    machine" count and a link to each part's drawing.
* **The model and the list stay in step.** When the design adds a part, its new
  `BOM_PART` marker appears in the count. The checker then reports "not placed by
  any step" until someone adds it to the sequence. When a quantity changes, the
  running totals catch it.
* **`status` tracks trust:**
  * `draft`: written from the model.
  * `checked`: desk-checked against the model.
  * `verified`: someone built it this way. Record who and when in `notes`.

## 4. The missing link: where each part goes

A manual needs to show *this particular* A4 angle being bolted to *this*
tube. Today the model only says "there are 26 A4s". The proposal is to give
every placed copy a **name**, using one small wrapper module:

```openscad
// openscad/bom.scad  (proposed)
STEP_SHOW = [];   // instance names to draw; [] = draw everything (normal renders)
STEP_NEW  = [];   // instance names to highlight as "added in this step"

module bom_part(id, instance) {
    echo(BOM_PART = id, INSTANCE = instance);   // replaces today's bare markers
    shown = STEP_SHOW == [] || len(search([instance], STEP_SHOW)[0]) > 0;
    if (shown)
        color(len(search([instance], STEP_NEW)[0]) > 0 ? "DarkOrange" : "LightGray")
        children();
}
```

Each call site in `lifetrac_v25.scad` changes mechanically:

```openscad
// before
translate([left_inner_panel_face, front_tube_rear_y, angle_z]) frame_tube_angle_iron();
// after
bom_part("A4", "frame/tube-front/left-inner/rear")
    translate([left_inner_panel_face, front_tube_rear_y, angle_z]) frame_tube_angle_iron();
```

* **Instance names** follow `subsystem/sub-assembly/side/position` and are stable,
  like step ids.
* **The instance list from the model** is one echo run (about half a second, the
  same as today's count). It is the full list of things that must be installed.
* **Steps can name instances with globs,** for example
  `add: [{part: A4, instances: ["frame/tube-*/*"]}]`. The checker then proves that
  every instance is installed **exactly once** and that each step names real
  instances. Counts per step are no longer typed by hand.
* **The step state reaches OpenSCAD on the command line:**
  `openscad -D 'STEP_SHOW=[...]' -D 'STEP_NEW=[...]'`. Normal renders are
  unaffected because both lists default to empty.

## 5. Rendering the pages

Two renderers are planned. They are built in order, and both are driven by the
same step list.

1. **Quick shaded version (OpenSCAD PNG).** For each step, render the machine
   with `STEP_SHOW` = everything installed so far and `STEP_NEW` = this step's
   instances. OpenSCAD's PNG export runs headless in CI under `xvfb`, the same
   way the existing `assembly.png` and animation workflows work. It is cheap and
   in colour, but raster only, and the camera must be given explicitly.
2. **IKEA-style line art (vector).**
   * Export each instance once, as an STL in world coordinates. Cache it by the
     part's geometry ID plus the instance's placement.
   * Run the hidden-line engine from the part drawings on the union of all
     installed instances. It draws:
     * old parts as thin grey lines,
     * new parts as bold black lines with a light fill,
     * correct occlusion between parts.
   * Output is a crisp vector PDF with no rendering farm.

Common to both:

* **Camera.** Each phase has a default view, and each step can override it with
  `view: {azimuth: 35, elevation: 25, zoom: new}`. `zoom: new` frames the new
  parts with some surrounding context. A "turn the model" icon is added when the
  view swings by more than 90°.
* **Motion arrows (exploded "action diagrams").** Each step can declare
  `motion: {parts: [T1, T2], direction: [1, 0, 0], distance: 400}`. The new parts
  are drawn pulled back along `direction`, with dashed guide lines and an arrow.
  Later, `direction` can default to the contact-face normal between the new part
  and parts already installed.
* **Callout boxes.**
  * Thumbnails reuse the isometric view from each part drawing, labelled with the
    part number and `xN`.
  * Hardware is drawn at 1:1 next to a length ruler.
  * Sub-assembly steps (`subassembly:` / `make:`) are drawn framed, with the `x2`
    badge, on the page of the step that `uses` them. Large ones get their own
    pages, as LEGO does.
* **Automatic icons.**
  * Two-person/hoist when a new part's calculated mass is over a set limit
    (e.g. 25 kg).
  * Welding when the step builds a weldment.
  * The jigs from `tools:`.
* **Output.** A PDF manual as a CI artifact, next to the drawing book. An HTML
  version with one step per screen would suit phones in the shop.

## 6. Checks the sequence makes possible later

* **Interference per step.** Each step's new parts must not overlap anything
  already installed. The repo already has
  [`tools/collision-check`](../tools/collision-check/) for pair checks.
* **Insertion path.** Sweep the new parts along `motion.direction` and check that
  nothing blocks them. This is what the robotics assembly-planning literature
  automates.
* **Tool access.** Is there wrench clearance around every bolt? This needs the
  bolts modelled (Phase 4).
* **Hole alignment.** Holes in mating parts should line up. The part drawings
  already find every hole in every part; with instance placements (section 4),
  mating holes can be matched in world coordinates. That would have caught the
  A6 segment mismatch now flagged on the drawings.

## 7. Roadmap

| Phase | Deliverable | Effort | Status |
|---|---|---|---|
| 0 | Editable step list + checker + numbered list + CI | small | **done (this PR)** |
| 1 | `bom.scad` `bom_part(id, instance)`; convert call sites; instance-level checks | medium (mechanical edits to `lifetrac_v25.scad`) | proposed |
| 2 | First manual: OpenSCAD PNG per step + callout boxes + PDF artifact | medium | proposed |
| 3 | IKEA line-art renderer, motion arrows, 1:1 hardware | medium-large | proposed |
| 4 | Bolts modelled at every joint (length from grip), exact hardware counts, torque values per step | medium | proposed |
| 5 | Automated interference / insertion / hole-alignment checks per step | large | proposed |

## 8. Questions for the team

1. Should the manual show **inches first or mm first**? The drawings currently
   show `mm [in]`.
2. Should it use **Letter or A4**? Should it have **1 step or up to 4 steps per page**?
3. Should it be **wordless** (IKEA), or keep a one-line title per step (current
   draft)?
4. Should steps have **photos of real builds** (`photos:` per step) once someone
   builds a machine this way? A photo marks the step as `verified`.
5. Which sub-assemblies do builders actually make on a bench (arms? bucket?), and
   which are built on the machine? This decides the callout boxes.

## Sources

* M. Agrawala, D. Phan, J. Heiser, J. Haymaker, J. Klingner, P. Hanrahan,
  B. Tversky. *Designing Effective Step-By-Step Assembly Instructions.* ACM
  Transactions on Graphics 22(3):828-837 (SIGGRAPH 2003).
  [ACM DL](https://dl.acm.org/doi/10.1145/1201775.882352) ·
  [paper PDF](https://courses.ischool.berkeley.edu/i247/f05/readings/Agrawala_Assembly_SIGGRAPH03.pdf)
* LPub3D, an LDraw editor for LEGO-style digital building instructions:
  <https://trevorsandy.github.io/lpub3d/> ·
  [callouts](https://sites.google.com/view/workingwithlpub3d/learning-the-basics/callouts)

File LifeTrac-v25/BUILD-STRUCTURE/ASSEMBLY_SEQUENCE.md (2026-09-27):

# LifeTrac v25 - Structural Assembly Sequence

> **Generated from [`assembly_sequence.yaml`](assembly_sequence.yaml). Edit that file, not this one.** Step numbers come from the order of the steps, so inserting or moving a step renumbers everything after it. Refer to steps by their `id`, which never changes. See [`ASSEMBLY_MANUAL_AUTOGEN.md`](ASSEMBLY_MANUAL_AUTOGEN.md) for how this list will drive a picture manual.

**DRAFT** - 24 steps (24 draft) - 158 of 158 fabricated pieces placed.

## Prepare the parts

### Step 1 - Cut, drill and deburr every part from its drawing and paint-pen its part number on it

`prep-cut-drill-mark` - draft

**Tools:** [**J1**](../DESIGN-STRUCTURAL/drawings/generated/pdf/J1_tube-drilling-jig.pdf), [**J5**](../DESIGN-STRUCTURAL/drawings/generated/pdf/J5_angle-iron-drill-jig.pdf), [**J6**](../DESIGN-STRUCTURAL/drawings/generated/pdf/J6_tube-drill-jig.pdf), drill press, chop saw or bandsaw, CNC plasma

> Drawings: DESIGN-STRUCTURAL/drawings/generated/INDEX.md. Read each sheet's CHECK BEFORE MAKING notes first; they list known model problems. Lay the parts out by phase.

## Base frame

### Step 2 - Bolt the bottom angle runs to the floor plate

`floor-angles` - sub-assembly: *Floor* - draft

| Add | Part | Qty | Placed so far | Per machine |
|---|---|---:|---:|---:|
| [**P7**](../DESIGN-STRUCTURAL/drawings/generated/pdf/P7_bottom-stiffener-plate.pdf) | Bottom stiffener plate | 1 | 1 | 1 |
| [**A6-1**](../DESIGN-STRUCTURAL/drawings/generated/pdf/A6-1_bottom-stiffener-angle-rear-segment.pdf) | Bottom stiffener angle, rear segment | 6 | 6 | 10 |
| [**A6-2**](../DESIGN-STRUCTURAL/drawings/generated/pdf/A6-2_bottom-stiffener-angle-middle-segment.pdf) | Bottom stiffener angle, middle segment | 6 | 6 | 10 |
| [**A6-3**](../DESIGN-STRUCTURAL/drawings/generated/pdf/A6-3_bottom-stiffener-angle-front-segment.pdf) | Bottom stiffener angle, front segment | 6 | 6 | 10 |

> Six runs of three segments, vertical leg up, one run along each side panel line. Check the A6 lengths against the plate holes first: the drawings flag a mismatch.

### Step 3 - Bolt the vertical angles to the back stiffener plate

`rear-wall` - sub-assembly: *Rear wall* - draft

| Add | Part | Qty | Placed so far | Per machine |
|---|---|---:|---:|---:|
| [**P4**](../DESIGN-STRUCTURAL/drawings/generated/pdf/P4_back-stiffener-plate.pdf) | Back stiffener plate | 1 | 1 | 1 |
| [**A1**](../DESIGN-STRUCTURAL/drawings/generated/pdf/A1_back-stiffener-outer-vertical-angle.pdf) | Back stiffener outer vertical angle | 2 | 2 | 2 |
| [**A2**](../DESIGN-STRUCTURAL/drawings/generated/pdf/A2_back-stiffener-inner-vertical-angle.pdf) | Back stiffener inner vertical angle | 4 | 4 | 4 |

### Step 4 - Bolt the angles to the three front stiffener plates

`front-wall` - sub-assembly: *Front wall* - draft

| Add | Part | Qty | Placed so far | Per machine |
|---|---|---:|---:|---:|
| [**P5**](../DESIGN-STRUCTURAL/drawings/generated/pdf/P5_front-stiffener-plate-centre.pdf) | Front stiffener plate, centre | 1 | 1 | 1 |
| [**P6**](../DESIGN-STRUCTURAL/drawings/generated/pdf/P6_front-stiffener-plate-outer.pdf) | Front stiffener plate, outer | 2 | 2 | 2 |
| [**A10**](../DESIGN-STRUCTURAL/drawings/generated/pdf/A10_front-stiffener-outer-angle.pdf) | Front stiffener outer angle | 8 | 8 | 8 |
| [**A4**](../DESIGN-STRUCTURAL/drawings/generated/pdf/A4_frame-tube-mount-angle.pdf) | Frame tube mount angle | 2 | 2 | 26 |

### Step 5 - Bolt the bottom angle runs and tube angles to each motor plate

`motor-plates` - sub-assembly: *Motor plate* x2 - draft

| Add | Part | Qty | Placed so far | Per machine |
|---|---|---:|---:|---:|
| [**P8**](../DESIGN-STRUCTURAL/drawings/generated/pdf/P8_motor-mounting-plate.pdf) | Motor mounting plate | 2 | 2 | 2 |
| [**A6-1**](../DESIGN-STRUCTURAL/drawings/generated/pdf/A6-1_bottom-stiffener-angle-rear-segment.pdf) | Bottom stiffener angle, rear segment | 4 | 10 | 10 |
| [**A6-2**](../DESIGN-STRUCTURAL/drawings/generated/pdf/A6-2_bottom-stiffener-angle-middle-segment.pdf) | Bottom stiffener angle, middle segment | 4 | 10 | 10 |
| [**A6-3**](../DESIGN-STRUCTURAL/drawings/generated/pdf/A6-3_bottom-stiffener-angle-front-segment.pdf) | Bottom stiffener angle, front segment | 4 | 10 | 10 |
| [**A4**](../DESIGN-STRUCTURAL/drawings/generated/pdf/A4_frame-tube-mount-angle.pdf) | Frame tube mount angle | 8 | 10 | 26 |

### Step 6 - Stand both inner side panels on the floor and bolt them to its angles

`inner-panels` - draft

| Add | Part | Qty | Placed so far | Per machine |
|---|---|---:|---:|---:|
| [**P3**](../DESIGN-STRUCTURAL/drawings/generated/pdf/P3_side-panel-inner.pdf) | Side panel, inner | 2 | 2 | 2 |

**Installs:** `floor-angles`

> Brace the panels square and plumb before tightening.

### Step 7 - Bolt the motor plates to the floor between the inner panels

`motor-plates-install` - draft

**Installs:** `motor-plates`  
**After:** `inner-panels`

### Step 8 - Slide the front and rear cross tubes through the panel windows and bolt on the tube angles

`cross-tubes` - draft

| Add | Part | Qty | Placed so far | Per machine |
|---|---|---:|---:|---:|
| [**T1**](../DESIGN-STRUCTURAL/drawings/generated/pdf/T1_front-frame-cross-tube.pdf) | Front frame cross tube | 1 | 1 | 1 |
| [**T2**](../DESIGN-STRUCTURAL/drawings/generated/pdf/T2_rear-frame-cross-tube.pdf) | Rear frame cross tube | 1 | 1 | 1 |
| [**A4**](../DESIGN-STRUCTURAL/drawings/generated/pdf/A4_frame-tube-mount-angle.pdf) | Frame tube mount angle | 16 | 26 | 26 |

**After:** `inner-panels`, `motor-plates-install`  
**Tools:** [**J1**](../DESIGN-STRUCTURAL/drawings/generated/pdf/J1_tube-drilling-jig.pdf)

### Step 9 - Fit the left and right outer side panels

`outer-panels` - draft

| Add | Part | Qty | Placed so far | Per machine |
|---|---|---:|---:|---:|
| [**P1**](../DESIGN-STRUCTURAL/drawings/generated/pdf/P1_side-panel-outer-left.pdf) | Side panel, outer, left | 1 | 1 | 1 |
| [**P2**](../DESIGN-STRUCTURAL/drawings/generated/pdf/P2_side-panel-outer-right.pdf) | Side panel, outer, right | 1 | 1 | 1 |

**After:** `cross-tubes`

> P1 goes on the left and P2 on the right. They are not interchangeable.

### Step 10 - Bolt the rear wall between the side panels

`rear-wall-install` - draft

**Installs:** `rear-wall`  
**After:** `outer-panels`

> The drawing flags an interference with the inner panels. Check the fit first.

### Step 11 - Bolt the front wall to the panels and motor plates

`front-wall-install` - draft

**Installs:** `front-wall`  
**After:** `outer-panels`, `motor-plates-install`

## Wheel units (UWU)

### Step 12 - Weld each wheel hub (DOM tube, lug plate and four gussets)

`hub-weldment` - sub-assembly: *Wheel hub* x4 - draft

| Add | Part | Qty | Placed so far | Per machine |
|---|---|---:|---:|---:|
| [**T7**](../DESIGN-STRUCTURAL/drawings/generated/pdf/T7_wheel-hub-dom-tube.pdf) | Wheel hub DOM tube | 4 | 4 | 4 |
| [**P17**](../DESIGN-STRUCTURAL/drawings/generated/pdf/P17_wheel-hub-lug-plate.pdf) | Wheel hub lug plate | 4 | 4 | 4 |
| [**P18**](../DESIGN-STRUCTURAL/drawings/generated/pdf/P18_wheel-hub-gusset.pdf) | Wheel hub gusset | 16 | 16 | 16 |

### Step 13 - Fit the shafts, bearings, motors and hubs on the motor plates

`wheel-drives` - draft

| Add | Part | Qty | Placed so far | Per machine |
|---|---|---:|---:|---:|
| [**R6**](../DESIGN-STRUCTURAL/drawings/generated/pdf/R6_wheel-shaft.pdf) | Wheel shaft | 4 | 4 | 4 |

**Installs:** `hub-weldment`  
**After:** `motor-plates-install`, `outer-panels`

> Bearings, couplings, hydraulic motors, rims and tyres are purchased and not in the parts manifest yet.

## Loader arms

### Step 14 - Weld the pivot plates to each pivot DOM tube

`pivot-mounts` - sub-assembly: *Arm pivot mount* x2 - draft

| Add | Part | Qty | Placed so far | Per machine |
|---|---|---:|---:|---:|
| [**T6**](../DESIGN-STRUCTURAL/drawings/generated/pdf/T6_arm-pivot-dom-tube.pdf) | Arm pivot DOM tube | 2 | 2 | 2 |
| [**P11**](../DESIGN-STRUCTURAL/drawings/generated/pdf/P11_arm-pivot-mount-plate.pdf) | Arm pivot mount plate | 4 | 4 | 4 |

**Tools:** [**J2**](../DESIGN-STRUCTURAL/drawings/generated/pdf/J2_pivot-mount-welding-jig-base.pdf), [**J3**](../DESIGN-STRUCTURAL/drawings/generated/pdf/J3_pivot-mount-welding-jig-ring.pdf), [**J4**](../DESIGN-STRUCTURAL/drawings/generated/pdf/J4_pivot-welding-spacer-jig.pdf)

### Step 15 - Bolt each arm together (main tube between inner and outer plates, pivot mount, crossbeam angles)

`arms` - sub-assembly: *Loader arm* x2 - draft

| Add | Part | Qty | Placed so far | Per machine |
|---|---|---:|---:|---:|
| [**T4**](../DESIGN-STRUCTURAL/drawings/generated/pdf/T4_arm-main-tube.pdf) | Arm main tube | 2 | 2 | 2 |
| [**P9**](../DESIGN-STRUCTURAL/drawings/generated/pdf/P9_arm-side-plate-inner.pdf) | Arm side plate, inner | 2 | 2 | 2 |
| [**P10**](../DESIGN-STRUCTURAL/drawings/generated/pdf/P10_arm-side-plate-outer.pdf) | Arm side plate, outer | 2 | 2 | 2 |
| [**A5**](../DESIGN-STRUCTURAL/drawings/generated/pdf/A5_arm-crossbeam-mount-angle.pdf) | Arm crossbeam mount angle | 4 | 4 | 4 |

**Installs:** `pivot-mounts`

### Step 16 - Join the arms with the crossbeam and pin on the bucket-cylinder base lugs

`crossbeam` - draft

| Add | Part | Qty | Placed so far | Per machine |
|---|---|---:|---:|---:|
| [**T3**](../DESIGN-STRUCTURAL/drawings/generated/pdf/T3_arm-crossbeam-tube.pdf) | Arm crossbeam tube | 1 | 1 | 1 |
| [**U1**](../DESIGN-STRUCTURAL/drawings/generated/pdf/U1_arm-crossbeam-cylinder-lug.pdf) | Arm crossbeam cylinder lug | 2 | 2 | 2 |
| [**R3**](../DESIGN-STRUCTURAL/drawings/generated/pdf/R3_clevis-pin-3-4.pdf) | Clevis pin 3/4 | 2 | 2 | 4 |

**Installs:** `arms`

### Step 17 - Hang the arm frame on the machine with the pivot pins

`hang-arms` - draft

| Add | Part | Qty | Placed so far | Per machine |
|---|---|---:|---:|---:|
| [**R2**](../DESIGN-STRUCTURAL/drawings/generated/pdf/R2_arm-pivot-pin.pdf) | Arm pivot pin | 2 | 2 | 2 |
| [**F1**](../DESIGN-STRUCTURAL/drawings/generated/pdf/F1_hex-nut-1-1-2-6.pdf) | Hex nut 1-1/2-6 | 4 | 4 | 4 |

**After:** `crossbeam`, `outer-panels`

> One 1-1/2 nut on each end of each pin.

## Bucket

### Step 18 - Tack and weld the bucket (back, bottom, sides, cutting edge)

`bucket-weldment` - sub-assembly: *Bucket* - draft

| Add | Part | Qty | Placed so far | Per machine |
|---|---|---:|---:|---:|
| [**P12**](../DESIGN-STRUCTURAL/drawings/generated/pdf/P12_bucket-back-plate.pdf) | Bucket back plate | 1 | 1 | 1 |
| [**P13**](../DESIGN-STRUCTURAL/drawings/generated/pdf/P13_bucket-bottom-plate.pdf) | Bucket bottom plate | 1 | 1 | 1 |
| [**P14**](../DESIGN-STRUCTURAL/drawings/generated/pdf/P14_bucket-side-plate.pdf) | Bucket side plate | 2 | 2 | 2 |
| [**P19**](../DESIGN-STRUCTURAL/drawings/generated/pdf/P19_bucket-cutting-edge.pdf) | Bucket cutting edge | 1 | 1 | 1 |

> The drawing flags that the side plates' tab slots are modelled only 1 mm deep. Cut them through.

### Step 19 - Weld the pivot and cylinder lugs to the bucket back

`bucket-lugs` - draft

| Add | Part | Qty | Placed so far | Per machine |
|---|---|---:|---:|---:|
| [**U2**](../DESIGN-STRUCTURAL/drawings/generated/pdf/U2_bucket-pivot-lug.pdf) | Bucket pivot lug | 2 | 2 | 2 |
| [**U3**](../DESIGN-STRUCTURAL/drawings/generated/pdf/U3_bucket-cylinder-lug.pdf) | Bucket cylinder lug | 2 | 2 | 2 |

**Installs:** `bucket-weldment`

### Step 20 - Pin the bucket to the arm tips

`bucket-mount` - draft

| Add | Part | Qty | Placed so far | Per machine |
|---|---|---:|---:|---:|
| [**R4**](../DESIGN-STRUCTURAL/drawings/generated/pdf/R4_bucket-pivot-pin.pdf) | Bucket pivot pin | 2 | 2 | 2 |

**After:** `hang-arms`, `bucket-lugs`

## Cylinders

### Step 21 - Pin the lift cylinders between the inner panels and the arms

`lift-cylinders` - draft

| Add | Part | Qty | Placed so far | Per machine |
|---|---|---:|---:|---:|
| [**R1**](../DESIGN-STRUCTURAL/drawings/generated/pdf/R1_lift-cylinder-base-pin.pdf) | Lift cylinder base pin | 2 | 2 | 2 |

**After:** `hang-arms`

> Hydraulic cylinders are purchased and not in the parts manifest yet.

### Step 22 - Pin the bucket cylinders between the crossbeam lugs and the bucket lugs

`bucket-cylinders` - draft

| Add | Part | Qty | Placed so far | Per machine |
|---|---|---:|---:|---:|
| [**R3**](../DESIGN-STRUCTURAL/drawings/generated/pdf/R3_clevis-pin-3-4.pdf) | Clevis pin 3/4 | 2 | 4 | 4 |

**After:** `bucket-mount`, `crossbeam`

## Folding operator platform

### Step 23 - Bolt the side and transverse angles to the deck

`platform-weldment` - sub-assembly: *Platform* - draft

| Add | Part | Qty | Placed so far | Per machine |
|---|---|---:|---:|---:|
| [**P15**](../DESIGN-STRUCTURAL/drawings/generated/pdf/P15_platform-deck.pdf) | Platform deck | 1 | 1 | 1 |
| [**A7**](../DESIGN-STRUCTURAL/drawings/generated/pdf/A7_platform-side-angle-arm.pdf) | Platform side angle arm | 2 | 2 | 2 |
| [**A8**](../DESIGN-STRUCTURAL/drawings/generated/pdf/A8_platform-transverse-angle.pdf) | Platform transverse angle | 2 | 2 | 2 |

### Step 24 - Hinge the platform to the inner panels and fit the lock pins

`platform-install` - draft

| Add | Part | Qty | Placed so far | Per machine |
|---|---|---:|---:|---:|
| [**P16**](../DESIGN-STRUCTURAL/drawings/generated/pdf/P16_platform-pivot-bracket.pdf) | Platform pivot bracket | 2 | 2 | 2 |
| [**R5**](../DESIGN-STRUCTURAL/drawings/generated/pdf/R5_platform-pivot-pin.pdf) | Platform pivot pin | 2 | 2 | 2 |
| [**F2**](../DESIGN-STRUCTURAL/drawings/generated/pdf/F2_platform-lock-pin-5-8.pdf) | Platform lock pin 5/8 | 2 | 2 | 2 |

**Installs:** `platform-weldment`  
**After:** `outer-panels`

## Parts not yet placed

Every fabricated part is placed exactly as many times as the model uses it.

Not yet assigned to steps (quantities are estimates, not counted in the model): F3, F4, F5, F6, F7, F8, F9, F10.

## Checks

- all good

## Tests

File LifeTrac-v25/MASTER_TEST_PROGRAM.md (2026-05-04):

# LifeTrac v25 — Master Test Program

**Status:** living document, updated every implementation round.
**Last updated:** 2026-05-04 (X8 M7 bring-up / W4-pre partial evidence).
**Owner:** every PR that adds, removes, or re-scopes a test MUST update
the relevant section of this file in the same commit. See
[§7 Update Protocol](#7-update-protocol).

This page is the **single index** for every test the LifeTrac v25
controller subsystem runs. It does NOT duplicate the implementation
plan, the HIL runbook, or the round-by-round status memo — it
links into them and answers three questions they don't:

1. **What tests exist today?** (catalog tables — §2, §3, §4)
2. **Which Implementation-Plan item (IP-XXX) does each test cover?** (§5)
3. **What is the gap between SIL coverage and the HIL bench?** (§4)

---

## Table of Contents

1. [Tier overview](#1-tier-overview)
2. [SIL test catalog](#2-sil-test-catalog)
3. [Compile-gate catalog](#3-compile-gate-catalog)
4. [HIL bench matrix](#4-hil-bench-matrix)
5. [Per-IP traceability](#5-per-ip-traceability)
6. [How to run](#6-how-to-run)
7. [Update protocol](#7-update-protocol)

---

## 1. Tier overview

The v25 controller is verified at three tiers. Each tier catches a
different class of regression — none of the three is sufficient on its
own.

| Tier | Where it runs | What it catches | Count (Round 20) |
|---|---|---|---|
| **SIL** (software-in-the-loop) | CI on every push, pure Python stdlib + project deps | Logic, protocol, state-machine regressions; cross-language byte-identity (C ↔ Python). **No hardware required.** | **581 tests** across [49 files](#2-sil-test-catalog) |
| **Compile gates** | CI on every push, `arduino-cli compile` against pinned cores | Toolchain drift, missing libraries, link errors, flash/RAM regressions, FQBN / sketch-folder convention breaks. | **5 jobs** (4 sketches × 1, plus stub/real-crypto on handheld) — [§3](#3-compile-gate-catalog) |
| **HIL** (hardware-in-the-loop) | Bench, manually, per [HIL_RUNBOOK.md](DESIGN-CONTROLLER/HIL_RUNBOOK.md) | Real-radio timing, valve-coil energise/release latency, RF link budget, IRQ jitter, on-air decode after cold-boot. | **12 procedures** — [§4](#4-hil-bench-matrix). The matrix opens with **W4-pre** (board bring-up sanity, no RF) and **W4-00** (dual-Portenta LoRa-stack bench) so board health is confirmed and the radio link is proven on real silicon before any valve-coil work is attempted. |

**Coverage rule:** every HIL bench item should have a SIL companion that
verifies the *logic* it depends on (state machine, threshold, ramp
shape, ladder transitions). The HIL run is then a *confirmation* that
the on-air / valve-coil reality matches the model — much faster to
diagnose when something fails. SIL coverage of a HIL item is documented
in [§4](#4-hil-bench-matrix).

---

## 2. SIL test catalog

All paths relative to [`LifeTrac-v25/DESIGN-CONTROLLER/base_station/tests/`](DESIGN-CONTROLLER/base_station/tests/).

| File | Tests | Scope | IP refs | W4 gate | Round |
|---|---|---|---|---|---|
| [test_accel_select.py](DESIGN-CONTROLLER/base_station/tests/test_accel_select.py) | 10 | Coral accelerator detection and state management. | — | — | — |
| [test_audit_log.py](DESIGN-CONTROLLER/base_station/tests/test_audit_log.py) | 5 | JSONL append-only audit log rotation and thread-safety. | — | — | — |
| [test_axis_ramp_sil.py](DESIGN-CONTROLLER/base_station/tests/test_axis_ramp_sil.py) | 10 | M7 proportional valve ramp timing + mixed-mode skip arbitration. Round 44 (BC-21): rewrote to operate on **logical** axes (`left_track`, `right_track`, `arms`, `bucket`) AFTER differential mixing; W4-05/W4-06 invariants preserved. | — | W4-05, W4-06 | 18, 44 |
| [test_track_mix_ramp_sil.py](DESIGN-CONTROLLER/base_station/tests/test_track_mix_ramp_sil.py) | 25 | BC-21 mix-then-ramp + K-A4 coordinated bilateral track stop: differential mixing math `leftTrack = clip(lhy + lhx, ±127)` + mirror across spin / smooth-curve / saturation cases (RT-A); per-side coil mapping energises correctly for spin-turns that pre-BC-21 produced zero coil activation (RT-B); smooth-curve turn (forward-pinned `lhy`, ramping `lhx` in) does NOT step the right track post-BC-21, with control-arm proving the pre-BC-21 short-circuit was visible (RT-C); K-A4 coordinated bilateral stop pins both track ramps to the larger starting magnitude's duration so the tractor doesn't pivot during release — symmetric, asymmetric, and same-tick zero-crossing all green (RT-D); single-track release does not falsely trigger K-A4 (RT-F); firmware source tripwire pins `BC-21` / `K-A4` / `clip_to_int8` markers, presence of new logical-axis globals, removal of pre-BC-21 stick-axis globals, and per-side coil-mapping pattern (RT-G). | — | (W4-05 augmented) | 44 |
| [test_reversal_brake_sil.py](DESIGN-CONTROLLER/base_station/tests/test_reversal_brake_sil.py) | 21 | BC-22 reversal brake: same-tick sign-flip on a still-energised axis converts the operator's reversal command into a decay-to-zero ramp using the standard release ladder, then holds the axis at zero for `REVERSAL_BRAKE_MS = 100` (2 × RAMP_TICK_MS) before the new direction is allowed to pass through. BR-A pins the decay phase shape (no snap to new direction; ramp uses release-ladder duration; magnitude is monotonically non-increasing across the decay window; brake window is armed at the deadline tick). BR-B pins the settle window invariants (effective stays at 0 for the full window even with the reversed stick still held; input changes during settle are ignored; constant equals 2 × RAMP_TICK_MS by design). BR-C pins post-brake resumption (new direction passes through immediately after window expiry; zero input post-brake leaves the axis at zero with no ghost ramp). BR-D pins the non-reversal cases that must NOT trigger BC-22 (same-sign magnitude jumps, plain release, sub-deadband flicker, mixed-mode-skip release). BR-E pins arm-axis reversals using the arm decay ladder while sharing the track settle window. BR-F is a firmware source tripwire for the `BC-22` marker, `REVERSAL_BRAKE_MS = 100` constant, `brake_until_ms` + `reversal_pending` struct fields, and the brake-arm / brake-clear code paths. | — | (extends W4-05 envelope) | 45 |
| [test_steering_priority_sil.py](DESIGN-CONTROLLER/base_station/tests/test_steering_priority_sil.py) | 24 | BC-23 preserve-steering + BC-24 spin-turn flow boost. SP-A pins the BC-23 helper math (`mix_tracks_preserve_steering` scales BOTH track intents by `127/max_mag` when either exceeds ±127): non-saturating identity, single-side saturation, both-sides saturation, sign preservation under negative saturation, mixed-sign saturation, just-above-threshold scaling, exact-127 boundary no-op, pure-throttle no-scale. SP-B pins the steering-ratio invariant end-to-end through `FourAxisArbiter`: across a sweep of saturating turns, the post-BC-23 differential is no further from the operator's commanded `lhx` than the pre-BC-23 independent-clip baseline; the saturating case `lhy=120, lhx=80` improves measurable differential authority. SP-C pins BC-24's spin-turn flow boost: pure spin (`lhy=0, lhx=120`) reaches the full 10000 mV flow set-point because the track contribution becomes `min(127, |left|+|right|) = 127`; partial spin uses sum-of-magnitudes; large spins clamp at int8 max. SP-D pins the non-spin cases that must NOT trigger the boost (forward / reverse / smooth-curve / arms-only — each must use the max formula). SP-E firmware source tripwire pins the `BC-23` + `BC-24` markers, the `mix_tracks_preserve_steering` helper, the absence of pre-BC-23 `clip_to_int8(left_track_raw)` pattern, and the `spin_turn` detection variable. | — | (extends W4-05 envelope) | 46 |
| [test_stick_curve_sil.py](DESIGN-CONTROLLER/base_station/tests/test_stick_curve_sil.py) | 20 | BC-25 / K-A2 per-stick response curve exponent. SC-A pins the pure `_apply_stick_curve(v, n)` math: identity at n=1.0 across the int8 range, zero is a fixed point at every supported exponent, full stick (±127) preserved at every exponent, n=2.0 maps 64→32 (square-law), n=1.5 lands strictly between linear and square at v=64, monotonic in input on [0, 127], sign preserved for non-trivial magnitudes, out-of-range inputs clamp rather than walk past the LUT. SC-B pins the default-identity contract: `FourAxisArbiter()` defaults to exponent 1.0 and produces the same byte-for-byte mixed outputs as the pre-BC-25 pipeline (legacy fixtures unaffected). SC-C pins the K-A2 motivating use case — at n=2.0 a 50%-stick input compresses to ~32 (vs 64 linear), and an arbiter run with `lhy=64` produces tracks of (32, 32). SC-D pins top-end authority: pegged sticks reach ±127 at n=1.0 / 1.5 / 2.0. SC-E pins that the curve applies **pre-mixing** — a pure `lhx=64` at n=2.0 produces tracks (32, -32), not the (16, -16) that post-mix curving would give. SC-F is a firmware/source tripwire pinning the `BC-25` marker, the `apply_stick_curve` symbol, the `init_stick_curve_lut` setup-time call, and the four call sites wrapping `cf.axis_lh_x` / `cf.axis_lh_y` / `cf.axis_rh_x` / `cf.axis_rh_y`; also pins the schema enum `[1.0, 1.5, 2.0]` and the `ui.stick_curve_exponent` row in `CAPABILITY_INVENTORY.md`. | — | (extends W4-05 envelope) | 48 |
| [test_ramp_shape_sil.py](DESIGN-CONTROLLER/base_station/tests/test_ramp_shape_sil.py) | 21 | BC-26 / K-A3 ramp interpolation shape selector. RS-A pins the `linear` default as byte-for-byte identical to the pre-Round-49 truncation formula `start * (duration - elapsed) / duration` across a representative spread of `start`, `duration_ms`, `elapsed` (positive, negative, quarter / half / three-quarter / endpoint elapsed); also pins that omitting the `shape` argument defaults to `linear`. RS-B pins the `scurve` endpoint contract: `elapsed=0 → start`, `elapsed≥duration → 0`, `duration=0 → 0`, monotonic non-increasing across the full ramp for positive `start`. RS-C pins the K-A3 closed-form quarter-points distinguishing `scurve` from `linear`: `t=0.25` smoothstep ≈ `0.854 × start` strictly higher than linear's `0.75`, `t=0.5` both shapes pass through `~0.5 × start`, `t=0.75` smoothstep ≈ `0.146 × start` strictly lower than linear's `0.25`. RS-D pins sign preservation for negative `start` and that the magnitude profile matches the positive case within 1 LSB of half-up rounding asymmetry. RS-E exercises `FourAxisArbiter(ramp_shape="scurve")` end-to-end: drive forward at `lhy=127`, release, capture every tick of the K-A4-coordinated 2 s release ramp; both shapes reach 0 at the deadline and `scurve` is strictly higher than `linear` at the quarter-point sample. RS-F pins the default-identity contract: `FourAxisArbiter()` with no `ramp_shape` argument produces byte-for-byte the same release trajectory as the explicit `linear` arbiter. RS-G is a firmware/source tripwire pinning the `BC-26` marker, the `ramp_interpolate` helper symbol, the `LIFETRAC_HYDRAULIC_RAMP_SHAPE_SCURVE` macro consumption, the helper call site replacing the pre-Round-49 inline interpolation, the schema `linear`/`scurve` enum, and the `hydraulic.ramp_shape` row in `CAPABILITY_INVENTORY.md`. | — | (extends W4-05 envelope) | 49 |
| [test_confined_space_sil.py](DESIGN-CONTROLLER/base_station/tests/test_confined_space_sil.py) | 18 | BC-27 / K-D2 confined-space mode (minimal version). CS-A pins the pure `ramp_duration_ms()` formula across the full ladder: `confined=False` matches the pre-Round-50 ladder byte-for-byte for both track (500 / 1000 / 2000 ms) and arm (250 / 500 / 1000 ms) magnitudes; `confined=True` multiplies by `3 / 2` (integer-exact: 250→375, 500→750, 1000→1500, 2000→3000); negative magnitudes treated as absolute. CS-B pins the default-identity contract: `FourAxisArbiter()` defaults `confined_space_mode_enabled=False` and produces byte-for-byte the same release-ramp trajectory as the explicit `False` arbiter. CS-C exercises a release ramp from `lhy=127` end-to-end: baseline last-non-zero tick ~38–40 (= 2000 ms / 50 ms tick), confined ~58–60 (= 3000 ms / 50 ms tick), and confined outlasts baseline by ≥ 18 ticks. CS-D pins K-A4 coordination under confined mode: drive `lhx=80, lhy=120` so the two pre-release magnitudes are asymmetric (left=127, right=25), then release; both tracks must read 0 at and beyond the K-A4 deadline tick (40 baseline / 60 confined) and stay there. CS-E composes BC-27 with BC-25 stick curve (`stick_curve_exponent=2.0`): both effects independently identifiable — curve compresses 64 → 32 at activation, confined-space mode stretches the subsequent release ramp. CS-F composes BC-27 with BC-26 scurve ramp shape: scurve still reaches 0 by the 3000 ms confined deadline (~tick 56–60), trajectory remains monotone non-increasing, and the quarter-point sample stays well above linear's `0.75 × start`. CS-G is a firmware/source tripwire pinning the `BC-27` marker, the `LIFETRAC_UI_CONFINED_SPACE_MODE_ENABLED` macro consumption, the `base * 3u` / `) / 2u` multiplier expression in `ramp_duration_ms()`, the schema `confined_space_mode_enabled` leaf, and the `ui.confined_space_mode_enabled` row in `CAPABILITY_INVENTORY.md`. | — | (extends W4-05 envelope) | 50 |
| [test_operator_profile_sil.py](DESIGN-CONTROLLER/base_station/tests/test_operator_profile_sil.py) | 21 | BC-28 / K-D1 operator profile preset (minimal). New enum leaf `ui.operator_profile` ∈ `{normal, gentle, sport}`, default `normal` = byte-for-byte identity (individual operator-feel leaves stand as authored). `gentle` overrides `ui.confined_space_mode_enabled = true` AND `hydraulic.ramp_shape = "scurve"`. `sport` overrides `ui.confined_space_mode_enabled = false`, `hydraulic.ramp_shape = "linear"` AND `ui.stick_curve_exponent = 1.0`. Overrides apply at config-load time inside `build_config.load()` via `_apply_operator_profile_overrides()`. OP-A pins the pure helper math: `normal` is a no-op (even when authored values would otherwise read as a bundle), `gentle` flips its two leaves regardless of authored values and leaves `stick_curve_exponent` alone, `sport` flips its three leaves regardless of authored values, sentinel fields under `ui`/`hydraulic`/`safety` stay untouched, an unknown profile is a defensive no-op (schema catches it upstream), and the public `OPERATOR_PROFILE_OVERRIDES` table is pinned exactly. OP-B exercises the loader integration via temp-TOML + `LIFETRAC_BUILD_CONFIG_PATH`: default `build.default.toml` yields `operator_profile == "normal"` with all three operator-feel leaves at identity values; a `gentle` toml that authors `confined_space_mode_enabled = false` still ends up `True` after load and `ramp_shape = "scurve"`; a `sport` toml that authors gentle settings ends up with all three sport overrides applied; `cfg.raw` reflects the post-override state so `config_sha256` is consistent across consumers (audit log, hot-reload diff, codegen). OP-C pins codegen integration: a `gentle` config emits `LIFETRAC_UI_CONFINED_SPACE_MODE_ENABLED 1` and `LIFETRAC_HYDRAULIC_RAMP_SHAPE_SCURVE 1` and `LIFETRAC_UI_OPERATOR_PROFILE "gentle"` + side macro; a `sport` config emits `..._CONFINED_SPACE_MODE_ENABLED 0`, `LIFETRAC_HYDRAULIC_RAMP_SHAPE_LINEAR 1`, `LIFETRAC_UI_STICK_CURVE_EXPONENT 1.0f`, and the sport side macro; a `normal` config (default toml) is byte-identity to the authored values. OP-D pins schema rejection of an unknown profile value (e.g. `"race_mode"`). OP-E is a source tripwire for the `BC-28` marker, `_apply_operator_profile_overrides` symbol + `OPERATOR_PROFILE_OVERRIDES` table in `build_config.py`, the schema enum, the `operator_profile = "normal"` line in `build.default.toml`, and the `ui.operator_profile` row in `CAPABILITY_INVENTORY.md`. | — | (extends W4-05 envelope) | 51 |
| [test_axis_deadband_sil.py](DESIGN-CONTROLLER/base_station/tests/test_axis_deadband_sil.py) | 23 | BC-29 / K-D3 configurable axis deadband. New int leaf `ui.axis_deadband` ∈ `[0, 32]`, default `13` (≈10% of int8 full scale) = byte-for-byte identity vs the pre-Round-52 hard-coded firmware constant. Firmware sources `AXIS_DEADBAND` from the codegen-emitted `LIFETRAC_UI_AXIS_DEADBAND` macro. DB-A pins schema validation: required-list update, in-range values 0/1/13/20/32 all accepted, out-of-range low (-1), out-of-range high (33), wrong type (string), and float-where-int-expected all rejected. DB-B pins default-value identity: default toml authors `axis_deadband = 13`, `cfg.ui.axis_deadband` is the int 13, codegen emits `LIFETRAC_UI_AXIS_DEADBAND 13`, and the leaf carries `reload_class = restart_required`. DB-C pins override round-trip: a temp toml authoring 5 / 0 / 32 round-trips through `build_config.load()` and the codegen header emits the corresponding macro value (5 case also pins that legacy `LIFETRAC_UI_AXIS_DEADBAND 13` does not appear). DB-D firmware tripwires pin: `BC-29` marker present, `AXIS_DEADBAND` initialised exactly as `(int8_t)LIFETRAC_UI_AXIS_DEADBAND`, the legacy `static const int8_t AXIS_DEADBAND = 13;` literal is gone, and the constant is still consumed in `axis_active()`, in the per-coil activation block (six track / arm patterns), in BC-24 spin-turn detection, and in the flow-set-point computation (both the threshold guard and the `(mag - AXIS_DEADBAND)` numerator). DB-E docs tripwires pin schema bounds (`"minimum": 0, "maximum": 32`), default-toml leaf + BC-29 doc comment, and the `ui.axis_deadband` row in `CAPABILITY_INVENTORY.md`. | — | (extends W4-05 envelope) | 52 |
| [test_ramp_heatmap_sil.py](DESIGN-CONTROLLER/base_station/tests/test_ramp_heatmap_sil.py) | 29 | K-E2 web UI ramp-state heatmap data model in [base_station/ramp_heatmap.py](DESIGN-CONTROLLER/base_station/ramp_heatmap.py). Per-axis, per-tick classification of the (raw, effective) pair into one of five states — `idle`, `matched`, `reversal`, `decay`, `mushy` — for the operator-visible "why did my stop feel mushy" overlay. RH-A pins the public `STATES` tuple shape so a regression that silently renames a state trips here. RH-B pins the signed `lag()` function (`raw - effective`). RH-C pins the precedence ladder of `classify_state()`: `idle` when both inputs are within `deadband`; `reversal` when both are active but opposite-sign (BC-22 territory — wins over `mushy` because reversal-brake lag is *expected*); `decay` when raw is idle but effective is still asserting (release ramp in flight); `mushy` when same-sign `|lag| > mushy_threshold`; `matched` otherwise. The boundary case (`|lag| == threshold`) classifies as `matched`; `|lag| == threshold + 1` classifies as `mushy`. Custom `deadband` and `mushy_threshold` overrides plumb through; both reject negative values with `ValueError`. RH-D pins `build_heatmap_row()` shape: five keys (`now_ms`, `raw`, `effective`, `lag`, `state`) all int-coerced (state is str). RH-E pins `build_heatmap()` top-level shape (`deadband`, `mushy_threshold`, `axes` keys), per-axis stream-order preservation, threshold override propagation, and a canonical pursuit-ramp scenario where a 127-floored stick climbs through 0 → 40 → 80 → 127 effective and produces `mushy / mushy / mushy / matched`. RH-F pins `DEFAULT_DEADBAND` to the BC-29 `ui.axis_deadband` config default, and pins `DEFAULT_MUSHY_THRESHOLD = 40` (~31% of int8 full scale) as the documented starting point. | — | (extends W4-05 envelope) | 53 |
| [test_motion_primitives_sil.py](DESIGN-CONTROLLER/base_station/tests/test_motion_primitives_sil.py) | 15 (1 skipped) | MP-01..MP-12 motion-primitive traceability. One test class per primitive in [DESIGN-KINEMATICS/MOTION_PRIMITIVES.md](DESIGN-KINEMATICS/MOTION_PRIMITIVES.md), each pinning the post-mix logical-axis signature through `FourAxisArbiter`. MP-01 / MP-02 (drive forward / reverse): both tracks equal sign, arms / bucket zero. MP-03 (skid turn): both tracks same sign, asymmetric, no spin-turn flow boost. MP-04 (pivot turn): one track exactly zero, other carries full mixed magnitude. MP-05 (spin in place): tracks opposite signs equal magnitude, BC-24 flow boost reaches 10000 mV. MP-06..MP-09 (arms / bucket only): single logical axis active, tracks zero. MP-10 (drive + arms): max-magnitude flow rule selects arms over track; single-EFC contention modelled. MP-11 (turn + bucket): pivot turn coexists with bucket, tracks and bucket independent; spin + bucket combined under spin-turn boost. MP-12 (float): build-gated by hydraulic.spool_type (BC-19); skipped with reason. Cross-cutting: sub-deadband inputs on all four sticks produce zero on every logical axis and zero flow_sp. | — | (extends W4-05 envelope) | 47 |
| [test_back_channel_dispatch.py](DESIGN-CONTROLLER/base_station/tests/test_back_channel_dispatch.py) | 12 | X8 back-channel dispatcher for camera control opcodes. | IP-104 | (W4-08 — partial) | — |
| [test_boot_phy_sil.py](DESIGN-CONTROLLER/base_station/tests/test_boot_phy_sil.py) | 11 | Boot-PHY first-frame decode: LADDER[0] + radio.begin() consistency across all nodes. | IP-006 | W4-07 | 20 |
| [test_build_config_loader_sil.py](DESIGN-CONTROLLER/base_station/tests/test_build_config_loader_sil.py) | 20 | Build-config loader + JSON Schema + canonical TOML round-trip: schema strict-object well-formedness, fallback-chain precedence (env→unit-id→default), strict validation (unknown / out-of-range / wrong-type / bad-enum / pattern / missing-section all raise), deterministic `config_sha256` (canonical-JSON formula, whitespace-invariant, leaf-change-sensitive), inventory-parity (schema↔CAPABILITY_INVENTORY.md no drift). | BC-01, BC-02 | — | 27 |
| [test_build_config_consumption_sil.py](DESIGN-CONTROLLER/base_station/tests/test_build_config_consumption_sil.py) | 11 | web_ui + lora_bridge consume BuildConfig at boot: `config_loaded` audit entries (unit_id / source_path / config_sha256), `_CAMERA_IDS` filtered against `cameras.{front,rear,implement,crop_health}_present` (canonical = auto+front, full = all five, count==0 = empty), `MAX_CONTROL_SUBSCRIBERS` reads from BUILD, graceful degradation when loader fails, source tripwires for BC-04 audit call in both daemons. | BC-04 | — | 28 |
| [test_build_config_delivery_sil.py](DESIGN-CONTROLLER/base_station/tests/test_build_config_delivery_sil.py) | 19 | BC-10 hot-reload contract: every schema leaf carries a `reload_class` annotation (enum-checked, `firmware_required` set pinned to `schema_version` + `safety.m4_watchdog_ms`); `diff_reload_classes` classifies live-only / restart-required / firmware-required changes and bubbles the strictest as `worst`; undeclared-leaf drift raises; `evaluate_quiescence` blocks on each of the four preconditions independently (parked seconds, control subscribers, M7 TX queue, engine load) with operator-facing reasons; loader/schema leaf-coverage parity; source tripwires for BC-10 helpers + `reload_class` keyword. | BC-10 | — | 29 |
| [test_build_config_installer_sil.py](DESIGN-CONTROLLER/base_station/tests/test_build_config_installer_sil.py) | 24 | BC-10 delivery (alpha): installer-bundle envelope (round-trip, filename pattern, body-tamper breaks SHA, version / unit_id / sentinel / filename mismatch all refused), `tools/lifetrac-config` CLI (validate / bundle / verify / diff with reload-class output), base-side `/config/download` route (PIN-gated, returns parseable bundle with documented Content-Disposition, emits `config_download` audit entry carrying the SHA), source tripwires for CLI subcommands + web route + `config_bundle` module. | BC-10 | — | 29b |
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

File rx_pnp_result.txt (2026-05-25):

Status             : OK
Problem            : CM_PROB_NONE
ProblemDescription :

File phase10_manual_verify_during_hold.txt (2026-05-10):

Password: sh: -c: option requires an argument

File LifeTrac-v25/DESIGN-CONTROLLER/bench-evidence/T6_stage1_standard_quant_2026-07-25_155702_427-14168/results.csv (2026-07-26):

cycle | launcher_rc | evidence_dir | final_result | elapsed_s | sync_ok | getid_ok | erase_ok | write_ok | verify_ok | boot_ok
1 | 0 | C:\Users\dorkm\Documents\GitHub\LifeTrac\LifeTrac-v25\DESIGN-CONTROLLER\bench-evidence\T6_stage1_standard_2026-07-25_205711 | PASS | 51 | 1 | 1 | 1 | 1 | 1 | 1
2 | 0 | C:\Users\dorkm\Documents\GitHub\LifeTrac\LifeTrac-v25\DESIGN-CONTROLLER\bench-evidence\T6_stage1_standard_2026-07-25_205812 | PASS | 51 | 1 | 1 | 1 | 1 | 1 | 1
3 | 0 | C:\Users\dorkm\Documents\GitHub\LifeTrac\LifeTrac-v25\DESIGN-CONTROLLER\bench-evidence\T6_stage1_standard_2026-07-25_205915 | PASS | 50 | 1 | 1 | 1 | 1 | 1 | 1

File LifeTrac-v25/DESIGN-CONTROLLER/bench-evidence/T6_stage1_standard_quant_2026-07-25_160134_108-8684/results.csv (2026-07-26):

cycle | launcher_rc | evidence_dir | final_result | elapsed_s | sync_ok | getid_ok | erase_ok | write_ok | verify_ok | boot_ok
1 | 0 | C:\Users\dorkm\Documents\GitHub\LifeTrac\LifeTrac-v25\DESIGN-CONTROLLER\bench-evidence\T6_stage1_standard_2026-07-25_210134 | PASS | 50 | 1 | 1 | 1 | 1 | 1 | 1
2 | 0 | C:\Users\dorkm\Documents\GitHub\LifeTrac\LifeTrac-v25\DESIGN-CONTROLLER\bench-evidence\T6_stage1_standard_2026-07-25_210226 | PASS | 50 | 1 | 1 | 1 | 1 | 1 | 1
3 | 0 | C:\Users\dorkm\Documents\GitHub\LifeTrac\LifeTrac-v25\DESIGN-CONTROLLER\bench-evidence\T6_stage1_standard_2026-07-25_210318 | PASS | 50 | 1 | 1 | 1 | 1 | 1 | 1

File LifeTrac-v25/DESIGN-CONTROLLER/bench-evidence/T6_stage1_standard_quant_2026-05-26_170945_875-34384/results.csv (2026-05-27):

cycle | launcher_rc | evidence_dir | final_result | elapsed_s | sync_ok | getid_ok | erase_ok | write_ok | verify_ok | boot_ok
1 | 1 | C:\Users\dorkm\Documents\GitHub\LifeTrac\LifeTrac-v25\DESIGN-CONTROLLER\bench-evidence\T6_stage1_standard_2026-05-26_220945 | FAIL_ID | 26 | 1 | 0 | 0 | 0 | 0 | 0
2 | 1 | C:\Users\dorkm\Documents\GitHub\LifeTrac\LifeTrac-v25\DESIGN-CONTROLLER\bench-evidence\T6_stage1_standard_2026-05-26_221012 | FAIL_ID | 4 | 1 | 0 | 0 | 0 | 0 | 0
3 | 1 | C:\Users\dorkm\Documents\GitHub\LifeTrac\LifeTrac-v25\DESIGN-CONTROLLER\bench-evidence\T6_stage1_standard_2026-05-26_221017 | FAIL_ID | 6 | 1 | 0 | 0 | 0 | 0 | 0

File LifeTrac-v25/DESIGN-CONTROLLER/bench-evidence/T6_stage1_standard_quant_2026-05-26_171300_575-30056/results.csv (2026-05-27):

cycle | launcher_rc | evidence_dir | final_result | elapsed_s | sync_ok | getid_ok | erase_ok | write_ok | verify_ok | boot_ok
1 | 1 | C:\Users\dorkm\Documents\GitHub\LifeTrac\LifeTrac-v25\DESIGN-CONTROLLER\bench-evidence\T6_stage1_standard_2026-05-26_221300 | FAIL_ID | 22 | 1 | 0 | 0 | 0 | 1 | 1
2 | 1 | C:\Users\dorkm\Documents\GitHub\LifeTrac\LifeTrac-v25\DESIGN-CONTROLLER\bench-evidence\T6_stage1_standard_2026-05-26_221322 | FAIL_ID | 19 | 1 | 0 | 0 | 0 | 1 | 1
3 | 1 | C:\Users\dorkm\Documents\GitHub\LifeTrac\LifeTrac-v25\DESIGN-CONTROLLER\bench-evidence\T6_stage1_standard_2026-05-26_221342 | FAIL_ID | 5 | 1 | 0 | 0 | 0 | 0 | 0

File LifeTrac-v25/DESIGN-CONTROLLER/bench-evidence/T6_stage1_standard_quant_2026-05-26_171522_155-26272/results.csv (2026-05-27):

cycle | launcher_rc | evidence_dir | final_result | elapsed_s | sync_ok | getid_ok | erase_ok | write_ok | verify_ok | boot_ok
1 | 1 | C:\Users\dorkm\Documents\GitHub\LifeTrac\LifeTrac-v25\DESIGN-CONTROLLER\bench-evidence\T6_stage1_standard_2026-05-26_221522 | FAIL_ID | 24 | 1 | 0 | 0 | 0 | 1 | 1
2 | 1 | C:\Users\dorkm\Documents\GitHub\LifeTrac\LifeTrac-v25\DESIGN-CONTROLLER\bench-evidence\T6_stage1_standard_2026-05-26_221547 | FAIL_ID | 5 | 1 | 0 | 0 | 0 | 0 | 0
3 | 1 | C:\Users\dorkm\Documents\GitHub\LifeTrac\LifeTrac-v25\DESIGN-CONTROLLER\bench-evidence\T6_stage1_standard_2026-05-26_221553 | FAIL_ID | 24 | 1 | 0 | 0 | 0 | 1 | 1

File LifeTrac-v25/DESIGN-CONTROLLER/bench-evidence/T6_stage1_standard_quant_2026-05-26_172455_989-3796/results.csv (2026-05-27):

cycle | launcher_rc | evidence_dir | final_result | elapsed_s | sync_ok | getid_ok | erase_ok | write_ok | verify_ok | boot_ok
1 | 1 | C:\Users\dorkm\Documents\GitHub\LifeTrac\LifeTrac-v25\DESIGN-CONTROLLER\bench-evidence\T6_stage1_standard_2026-05-26_222456 | FAIL_ID | 17 | 1 | 0 | 0 | 0 | 0 | 0

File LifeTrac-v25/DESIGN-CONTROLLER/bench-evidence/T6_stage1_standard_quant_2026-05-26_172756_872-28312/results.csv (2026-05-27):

cycle | launcher_rc | evidence_dir | final_result | elapsed_s | sync_ok | getid_ok | erase_ok | write_ok | verify_ok | boot_ok
1 | 1 | C:\Users\dorkm\Documents\GitHub\LifeTrac\LifeTrac-v25\DESIGN-CONTROLLER\bench-evidence\T6_stage1_standard_2026-05-26_222757 | FAIL_ID | 13 | 1 | 0 | 0 | 0 | 0 | 0

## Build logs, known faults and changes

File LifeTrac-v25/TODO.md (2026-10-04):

# LifeTrac v25 — TODO

> **🟢 Radio status (2026-08-17) — both loss-floor campaigns resolved.**
> The bench LoRa link runs at **0.9 % fragment loss** (single post-fix
> strict-hold verification leg L, archive
> `radio_monitor_20260817_195107_dde2c8a7`; day-to-day strict-hold range
> since: 0.9–1.6 %; from 5.9 % two days prior). RS-11.6: two external ISM emitters characterized (a ~7 s hopper
> and an exact-10 s device at −30 dBm — per the 2026-08-16 surveys; the
> 2026-08-22 dwell found −30 dBm at 923.5 riding the ~7 s grid and did
> NOT directly re-confirm the exact-10 s fingerprint); escaped by
> carrier choice — the
> band reshuffles in HOURS, so channel picks come from a same-day survey
> (`channel_survey_sniff.py` + `survey_compare.py`; 927.5 MHz was 3/3
> clean at this writing — **now 4/4**, see the 2026-08-22 session block
> below). RS-12: the historic slot-(total−2) loss was
> an L072 URC-overwrite race at the short-final-fragment ride; host-side
> mitigation: plain hold validated n=3 (1.8 %); the full strict hold
> (`-NoParkLast 1` **plus** `LIFETRAC_NO_PARK_LAST_GAP_MS=80`) has one
> leg per build — leg K 1.5 % pre-fix, leg L 0.9 % on the shipped code —
> env-gated, NOT a default (see the RS-12 closed entry). Remaining: one
> confirmation-sized flash session (rx_urc_lost + firmware URC fix —
> the RS-3.6 formal gate is NOT part of it, it was cleared 2026-07-25
> per `RS_firmware_patch_flash_2026-07-25/NOTES.md`, review catch) and
> the instrumented camera MOTION leg (the camera legs themselves flew
> 2026-08-22, see the session block below). Live campaign state:
> [DESIGN-CONTROLLER/TODO.md](DESIGN-CONTROLLER/TODO.md) (RS-12 / RS-12.9
> sequencing), issues #98/#107, evidence under
> `DESIGN-CONTROLLER/bench-evidence/`.
>
> **Update 2026-08-22:** production power-down/wake design opened (PR
> #110, [DESIGN-CONTROLLER/POWER_MANAGEMENT.md](DESIGN-CONTROLLER/POWER_MANAGEMENT.md)
> — Opta I1 key-off sensing, battery-bridged clean halt, default-off
> bench gating, base quiesce + hail-set rendezvous; tracked as PM-1).
> Its review surfaced a survey gap now tracked as **RS-11.8**: all bench
> stability data sits on the x.0/x.5 MHz grid, while the production FHSS
> table's 50 centers sit on x.25/x.75 — no shared channel, so production
> hop/hail picks need chantab-grid surveys.
>
> **Session 2026-08-22 (PR #111): camera legs at the RS-12 operating
> point — first live-traffic NO_PARK_LAST exercise.** *(Framing
> corrected in review: NOT the path's first flight — RS-3.3 flew
> 2026-07-31 with 2.4 KB multi-fragment keyframes,
> `RS_3_3_real_camera_2026-07-30/`; the 08-17 "never been on air" note
> was wrong. What remains unexercised is multi-frag camera trains UNDER
> the strict hold — the motion leg.)* *(Merge order: this TODO update
> references evidence, code, and design docs that land with PRs #110
> and #111 — merge those two first so nothing below dangles.)* Three 300 s legs at 927.5 MHz: 0.0 % (campaign-first zero
> leg), 0.3 %, 0.2 % with 11 injected keyframe requests landing in-leg
> (22 ×2-copy receptions; the injector emitted 12 of its 24 configured
> before being stopped at teardown — 1 landed post-leg, 12 never sent)
> dispatched during live traffic (first command-plane evidence for
> NO_PARK_LAST; the hold setting is transcript-attested, not
> archive-recorded — instrumented forward in PR #111). Residue: multi-fragment camera trains need
> scene motion at the bench. Same day: 927.5 became clean **4/4** — the
> sole stable channel across all surveys; the first chantab-grid pass
> proved ticker-dominated (no valid single-survey pick, method fix in
> RS-11.8); synth control 1.6 % with penultimate at 3 % (RS-12 fix
> holds); main CI red-since-#108 healed by #111's `_env_int` fix. Boards
> quiesced: Linux up, radios verified in LoRa SLEEP.
>
> **Sessions 2026-08-24 → 2026-09-07 (PRs #112, #114) — the hold is
> verified on air, and its limit is found.** 08-24: the archive
> instrumentation proved faithful (recorded `no_park_last` and the
> mechanism signature flip together: 1.5 %/6 % vs 3.3 %/35 %); a
> leg-report tool bug that could hide a 35 % lock behind one corrupt
> byte was fixed; the survey-ranked production channel (927.25) was
> **refuted by a link leg** (2.3× the loss of 927.5 — the ticker sits on
> it), so no hail constant comes from passive ranking any more. 09-06:
> the **motion leg flew** — camera + moving scene, 0.3 % loss, image
> watched live on the base website. 09-07: the long-train attempt found
> two things — camera keyframes are ~500 B at the current encoder
> point regardless of scene (long camera trains are an encoder-config
> axis, RS-3.11), and **under 145 live commands the strict hold is no
> longer loss-free (4.1 %, penultimate-of-two losses 12/14, RF
> unchanged): command/ack URCs are a second writer the hold cannot
> stop → `NO_PARK_LAST` default: do NOT flip; the flash session's
> `rx_urc_lost` + firmware URC fix is now the decisive item.** Also:
> the harness SWD-resets the tractor L072 at launch (base brackets
> only), quiesce held 13 days, stale scan floods under motion
> (RS-4.15). *(Merge order: #112 and #114 carry the evidence this
> references — merge them before this TODO update.)*

> **🟢 Milestone (2026-05-26) — image-over-LoRa air link proven end-to-end:**
> Tractor camera → tile-delta encode → MQTT (intra-X8) → image_tx_daemon →
> Murata L072 → 915 MHz LoRa → base L072 → image_rx_daemon → MQTT
> (intra-X8) → web_ui `/ws/state` → browser `<canvas id="image-canvas">`.
> Sustained zero-fragment-loss P-frame runs at SF7/BW500, `frames_published`
> climbing on the base, "2 Hz · tile stream" badge live in the UI. Final
> visual-pixel confirmation in the browser pending a base-X8 power cycle.
> Full status + open blockers (B1–B6):
> [AI NOTES/2026-05-26_Image_Over_LoRa_AirLink_Proven_Status_Copilot_v1_0.md](AI%20NOTES/2026-05-26_Image_Over_LoRa_AirLink_Proven_Status_Copilot_v1_0.md).
>
> **📦 First-release packaging plan (2026-05-26) — v25.0.1-bench:**
> Recommendation = git tag + a single combined `LifeTrac-v25/RELEASE/v25.0.1-bench/`
> manifest directory (Dockerfiles, compose, L072 firmware binaries + sha256,
> install.sh, SBOM, release notes). **Do not** create `TractorCodeV25.0.1/` /
> `BaseStationCodeV25.0.1/` duplicate source trees. Code triage (~70 % ships,
> ~20 % dev/diagnostic, ~10 % retire to `_retired/`), 10-step cut-the-tag
> runbook, image-compression-protocol readiness, and direct answers to the
> user's release questions are all in:
> [AI NOTES/2026-05-26_v25.0.1_Release_Packaging_Plan_Copilot_v1_0.md](AI%20NOTES/2026-05-26_v25.0.1_Release_Packaging_Plan_Copilot_v1_0.md).
>
> **� New blocker (2026-05-22 17:15) — P8:** First post-reflash W1-11
> ping_pong run failed 5/7 gates (`radio_tx_ok=0/100`, no RX frames). Root
> cause: commit `d4dfcb8` (2026-05-20) added `-DLIFETRAC_FHSS_TX_ROUTED=1`
> to `murata_l072/Makefile`; current `firmware.bin` therefore refuses every
> `TX_FRAME_REQ` with `HOST_ERR_PROTO_FORBIDDEN` until the host arms a
> profile via `cfg_set(CFG_KEY_REG_PROFILE=0x14, …)` — which no bench probe
> currently does. RX side fails symmetrically with
> `HOST_FAULT_CODE_RX_SCAN_FAILED (0x0D)`. **All RF testing (W1-10b, W1-11,
> W2-02, T4/T5b RF half) is blocked.** Three fix options (host-side /
> firmware-side / build-variant) need user direction before applying — see
> [AI NOTES/2026-05-22_W1-11_RF_Blocked_FHSS_Gate_v1_0.md](AI%20NOTES/2026-05-22_W1-11_RF_Blocked_FHSS_Gate_v1_0.md)
> and the new P8 entry in
> [AI NOTES/2026-05-21_Open_Problems_To_Fix_v1_0.md](AI%20NOTES/2026-05-21_Open_Problems_To_Fix_v1_0.md).
> Evidence dir:
> `DESIGN-CONTROLLER/bench-evidence/W1-11_pingpong_2026-05-22_165144/`.
> Note: the earlier P1 closure (below) is still valid — but only for the
> CFG_GET-only cold-boot discriminator. It does **not** prove RF I/O.
>
> **�🟢 Recent closure (2026-05-22):** P1 cold-boot stale-firmware regression
> is **CLOSED** after re-flashing both X8 boards with current `firmware.bin`.
> Two bugs fixed along the way: `stm32_an3155_flasher.py` termios import is
> now optional (LmP Python lacks `termios`); `run_flash_l072.sh` now
> **unexports** gpio8/10/15 immediately before launching `openocd` to avoid
> a sysfs/mmap race in the newer (`2025-07-14`) OpenOCD build on RX X8 that
> manifested as `SWD DPIDR 0xdeadbeef`. Post-reflash discriminator on RX
> shows clean `RUNTIME_PROFILE_ENUM=0` on 5/5 cycles. See
> [AI NOTES/2026-05-22_RX_Reflash_And_P1_Resolution_v1_0.md](AI%20NOTES/2026-05-22_RX_Reflash_And_P1_Resolution_v1_0.md)
> and the updated
> [AI NOTES/2026-05-21_Open_Problems_To_Fix_v1_0.md](AI%20NOTES/2026-05-21_Open_Problems_To_Fix_v1_0.md)
> closure table.
>
> **⚡ Controller architecture update (2026):** The primary controller design
> is now the three-tier Portenta Max Carrier + MKR WAN 1310 system documented
> in [DESIGN-CONTROLLER/ARCHITECTURE.md](DESIGN-CONTROLLER/ARCHITECTURE.md).
> All hardware-purchase, firmware, and bring-up tasks for that design live in
> [DESIGN-CONTROLLER/TODO.md](DESIGN-CONTROLLER/TODO.md).
>
> The Opta / ESP32 / Raspberry Pi prototype code referenced below has been
> moved to
> [DESIGN-CONTROLLER/RESEARCH-CONTROLLER/](DESIGN-CONTROLLER/RESEARCH-CONTROLLER/)
> (see its [README](DESIGN-CONTROLLER/RESEARCH-CONTROLLER/README.md)).
> The safety bug-fixes listed in this file are still worth completing on
> the prototype code if it gets used for any further bench tests, but the
> equivalent safety logic must be implemented from the start in the new
> Portenta firmware (tracked in [DESIGN-CONTROLLER/TODO.md § Phase 4](DESIGN-CONTROLLER/TODO.md#phase-4--tractor-firmware)).
> Path links below refer to the historical locations; prepend
> `DESIGN-CONTROLLER/RESEARCH-CONTROLLER/` for the current location of any
> Opta / ESP32 / `raspberry_pi_web_controller` files.

## 2026-04-28 controller code-review implementation plan

Four code reviews of the DESIGN-CONTROLLER stack (Claude Opus 4.7, GitHub
Copilot v1.0, GPT-5.3-Codex v1.0, Gemini 3.1 Pro) have been merged into a
single actionable plan with stable IDs (`IP-001` … `IP-309`) and severity
tags. **All work tracked there:**

➡️ **[AI NOTES/2026-04-28_Controller_Code_Review_Implementation_Plan_v1_0.md](AI%20NOTES/2026-04-28_Controller_Code_Review_Implementation_Plan_v1_0.md)**

**Test inventory & per-IP traceability:** the canonical index of every
SIL test, every Arduino compile gate, every HIL bench item, and which
IP each one verifies lives in
➡️ **[MASTER_TEST_PROGRAM.md](MASTER_TEST_PROGRAM.md)** —
update it in the same PR as any test/code change (see §7 of that file
for the protocol).

---

## 2026-05-18 TX-power adaptation + SAFETY-burst implementation plan

Design doc + six review passes (Gemini 3.1 Pro, GPT-5.3-Codex, three Claude
Opus 4.7 passes, GitHub Copilot) converged on 16 decisions (D1–D16) and 5
internal contradictions (C1–C5). Full source-of-truth:

➡️ **[AI NOTES/2026-05-18_TX_Power_Adaptation_And_Safety_Burst_Design_Copilot_v1_0.md](AI%20NOTES/2026-05-18_TX_Power_Adaptation_And_Safety_Burst_Design_Copilot_v1_0.md)**
(see §21.1 decision table, §21.2 contradictions, §21.3 gaps, §23.6 order)

Work is sequenced as **stages S0–S7**. Each stage has one deliverable + one
falsification gate; the next stage does not start until its predecessor's
gate passes on bench and evidence is committed under
`DESIGN-CONTROLLER/bench-evidence/`.

**Sequencing rule:** S2 is a hard blocker for S4 (the E-STOP replay-rejection
bug makes the 5-copy SAFETY burst actively dangerous — every burst copy
after the first is rejected as a replay, so the burst *reduces* assert
probability instead of raising it). S0+S1 are independent of firmware and
can run in parallel with S2.

**Bench hardware reality (updated 2026-05-19):** the LoRa-stack hardware
on the bench is **two Portenta X8 + Max Carrier boards and one camera**.
Each Max Carrier carries an onboard **Murata CMWX1ZZABZ-078**
(= STM32L072 + SX1276 SiP), so the two boards together ARE the production
radio set: **one Max Carrier is the base-station radio, the other is the
tractor-side radio.** The MKR WAN 1310 handheld referenced in earlier
revisions of this plan is **optional and not on the critical path**.

**Test-equipment scope (project decision 2026-05-19):**
- **No spectrum analyzer, no calibrated antenna, no TCB lab access.**
  FCC §15.247 EIRP compliance ships under **conducted-path datasheet
  declaration + firmware-side TX-power cap** (no lab-measured EIRP
  evidence). See S-HW.4 (permanently skipped) and S4.2 below.
- **No step attenuator.** S1.1 walk-power, S4 PER induction, S6
  margin-limited induction will substitute **range-walk + natural path
  loss** for controlled attenuation. See S-HW.2 (permanently skipped).
- **E-STOP model (revised 2026-05-19):** tractor-side E-STOP signal =
  **Arduino Opta digital input flip** routed to the base-station Max
  Carrier; operator-side E-STOP = **keyboard / joystick button on web
  remote controller UI**. No physical mushroom button required at the
  handheld; the Opta itself can carry a mushroom-button in a later
  hardening pass without re-architecting the signal path. See S-HW.5.

Every stage below is therefore tagged:

- 🟢 **HW-READY** — can complete on current bench (software-only or X8-only or 2× Max Carrier).
- 🟡 **HW-PARTIAL** — software foundations can be built now; final gate needs the Opta + web-UI button wiring (S-HW.5).
- ⚫ **HW-WAIVED** — originally required lab test-equipment we have
  permanently decided not to acquire (spectrum analyzer, step
  attenuator); ships under software-only enforcement + datasheet
  declaration. NOT a blocker.

Strategy: drive every 🟢 and the software half of every 🟡 to done now;
the full radio link (W1-10b) is already proven end-to-end on the 2× Max
Carrier pair. See "S-HW" and "Software-only work that can run NOW"
sections at the bottom of this plan for ordered next steps.

**Cross-doc precedence (add to design-doc top in S0, per §23.3):** when
docs disagree, implementation follows (1) current code constants + measured
bench evidence, (2) `DESIGN-CONTROLLER/DECISIONS.md`, (3) `LORA_PROTOCOL.md`,
(4) `IMAGE_PIPELINE.md`, (5) the 2026-05-18 design doc.

### Stage S0 — Document consolidation (editorial, no code) 🟢 HW-READY
- [x] **S0.1** Fix C1: §3.8 silence default 250 ms → 500 ms ship; 250 ms
      behind bench flag. — **DONE 2026-05-18** (strikethrough preserves
      original for review-trail integrity).
- [x] **S0.2** Fix C2: §3.9 recommendation Option U → **Option T** for
      product; Option U as migration shim. — **DONE 2026-05-18.**
- [x] **S0.3** Fix C3: §3.5 — all "H7 host (operator side)" language
      removed; adapter is X8 Python on both ends. Section title updated.
      — **DONE 2026-05-18** (§4 ASCII diagram label "Operator H7" not yet
      redrawn; tracked under S0.6 deferred follow-up).
- [x] **S0.4** Fix C4: §4 image-traffic row → "plaintext + 4 B seq + 2 B
      CRC32 (+6 B, no MAC)". SAFETY power "+17 dBm forced" → "regional
      EIRP cap per §21.3-6". — **DONE 2026-05-18.**
- [ ] **S0.5** *(deferred from surgical pass)* Renumber duplicate `## 13`,
      `## 14`, `## 15`, `## 18` headings. Requires audit of every
      `§13.x`-style cross-reference in §12–§23 first; defer until full
      consolidation pass.
- [ ] **S0.6** *(deferred from surgical pass)* Promote §15.3 P0/P1/P2/P3
      policy table into §4 as the canonical traffic-class table (replacing
      `STREAM_*`). §4 row labels were tagged inline with their P0–P3
      equivalents in S0.4 as a transitional step; full promotion + ASCII
      diagram redraw is the larger follow-up.
- [x] **S0.7** Add §23.3 precedence rule at top of design doc. — **DONE
      2026-05-18.**
- [x] **S0.8** Replace "20% P0 PER target" → "field gate <1% PER, recovery
      trigger before 2%". — **DONE 2026-05-18** (folded into §4 row edit).
- **Gate:** document reads top-to-bottom without contradicting itself.
  **Status (2026-05-18):** C1–C5 surgical fixes ✅ complete. Structural
  cleanup (S0.5, S0.6) still pending; doc line count is 2743 (up slightly
  from 2687 because the change-log footer was appended). Trim toward
  ~1200 lines after S0.5/S0.6 land.

### Stage S1 — Bench instrumentation (read-only firmware) 🟡 HW-PARTIAL
*(Software half can be built now on the two X8 boards; RF half requires
L072 + handheld reattached.)*
- [x] **S1.0** *(software-only)* ~~Implement
      `DESIGN-CONTROLLER/base_station/lora_airtime.py` — pure-Python ToA
      predictor `lora_time_on_air_ms(sf, bw, cr, payload_len, ...)`
      matching Semtech SX1276/SX1262 datasheet formulas, plus
      `encrypted_payload_len(class, raw_len, crypto_profile)` helper.~~
      **DONE 2026-05-18.** Discovery showed `lora_time_on_air_ms` and
      `encrypted_payload_len` already existed in `lora_proto.py`, so
      instead of creating a duplicate `lora_airtime.py` module we
      **extended `lora_proto.py`** with a `CryptoProfile` registry
      (`CRYPTO_GCM128_EXPLICIT` +28 B / `CRYPTO_GCM64_IMPLICIT` +12 B /
      `CRYPTO_IMAGE_PLAIN_CRC32` +6 B) and a backward-compatible
      `profile=` arg on `encrypted_payload_len`. Six new tests in
      `tests/test_lora_proto.py` pin the §17/§19 worked-example numbers
      (46.208/33.408 ms control, 28.224/23.104/20.544 ms image,
      524.800 ms telemetry) and assert that the shipped GCM-128 image
      profile MUST violate the 25 ms cap (sentinel test — guards D13/D14
      motivation). 24/24 lora_proto tests pass; 846/846 base_station
      tests pass (the 12 unrelated pre-existing failures in
      `test_fleet_key_provisioning_sil.py` and one `test_x8_encode_mode`
      case are infrastructure, not from this change). NOTE: §17 quoted
      557.57 ms for 100 B telemetry but the project's PHY_TELEMETRY
      (preamble=12) actually gives 524.800 ms — codebase is source of
      truth; doc footnote needs updating in a follow-up S0 doc-cleanup
      pass.
- [x] **S1.1** Add `walk_power` mode to
      `method_h_stage2_tx_probe_v2.py`: sweep 2 → 17 dBm in 1 dB steps,
      log RSSI/SNR/PER/CRC to CSV under `bench-evidence/walk_power_<date>/`.
      *(Code lands now; sweep run blocked until L072 reattached.)*
      *(DONE 2026-05-18 — new `run_walk_power()` + `--probe walk_power`
      mode in `method_h_stage2_tx_probe_v2.py`. CLI flags `--power-min`
      (default 2) / `--power-max` (default 17) / `--power-step` (default 1) /
      `--per-step-count` (default 100) / `--walk-payload-len` (default 16) /
      `--csv-out`. Per step issues `CFG_SET_REQ(CFG_KEY_TX_POWER_DBM=0x01,
      dbm)`, snapshots `radio_tx_ok/_abort_lbt/_abort_airtime`, sends N
      `TX_FRAME_REQ`s, captures `TX_DONE_URC` `status / time_on_air_us /
      tx_power_dbm` per frame, then writes one CSV row
      `(timestamp, step_idx, power_dbm_requested, power_dbm_echoed_first,
      count_sent, tx_done_ok, tx_done_fail, tx_timeout, radio_tx_ok_delta,
      radio_tx_abort_lbt_delta, radio_tx_abort_airtime_delta,
      mean_toa_us, tx_per_pct, rx_per_pct, rx_rssi_dbm_mean,
      rx_snr_db_mean, rx_crc_err_count)`. RX-side columns are emitted
      empty — a paired `--probe rx_listen` orchestrator running on the
      second board fills them post-sweep (see S1.4). Default output dir
      `bench-evidence/walk_power_<YYYY-MM-DD_HHMMSS>/walk_power_tx_side.csv`.
      Smoke-tested: `py method_h_stage2_tx_probe_v2.py --help` shows the
      new mode + flags; module imports clean. **First paired sweep landed
      2026-05-19** — see [bench-evidence/walk_power_pilot_2026-05-19/](DESIGN-CONTROLLER/bench-evidence/walk_power_pilot_2026-05-19/README.md);
      both L072s alive, 16-step 2..17 dBm sweep on 915.000 MHz with mean
      PER 0.59 %, RSSI monotonic, `__PAIRED_SWEEP_VERDICT__=OK`.)*
- [x] **S1.2** Instrument host orchestrator to record per-class p50/p99
      `TX_DONE` latency, P0 TX-start delay, queue age, measured-vs-predicted
      encrypted ToA. *(Hooks land now; data collection blocked until L072
      reattached.)*
      *(Host hooks DONE 2026-05-18 — new `tx_latency_meter.py` module
      defines `TxLatencyMeter` with `mark_enqueue / mark_dequeue /
      mark_done(predicted_toa_ms=…)` and per-class rolling p50/p99
      windows for queue_age, tx_done, and toa_delta. Wired into
      `Bridge._tx` (enqueue token) and `Bridge._tx_worker`
      (dequeue + done timestamps); all calls wrapped in try/except so
      instrumentation never breaks TX. Pinned by 14 tests in
      `test_tx_latency_meter.py` covering empty/lifecycle/per-class
      isolation/P0 p99 tail/missing-done/unknown-token/leak-guard/
      reset/rolling-window. **Real-airtime data still blocked on
      L072 reattach** — `predicted_toa_ms` is passed as `None` from
      the bridge for now; once `TX_DONE_URC (0x90)` is plumbed back
      from the L072 we substitute the real on-air timestamp and the
      ledger's PHY airtime prediction.)*
- [x] **S1.3** Extend topic `0x10` decoder + add `newest_frame_wins` counter
      to W2-02 stability harness (preparation for S3 validation).
      *(Decoder/counter land now; validation run blocked.)*
      *(DONE 2026-05-18 — two new pure-Python modules: (1)
      `topic_0x10_decoder.py` defines `decode_topic_0x10()` →
      `SourceActiveSnapshot` normalising legacy 1-byte enum, JSON
      dict, and forward-rev payloads; preserves unknown keys in
      `extras`; fail-closed on garbage. (2) `newest_frame_wins.py`
      defines `NewestFrameWinsCounter` with RFC-1982 16-bit
      serial-arithmetic accept/stale/duplicate counters per
      AI NOTES 2026-05-18 §"newest-frame-wins gate". Counter wired
      into `w2_02_host_pipeline.py::cmd_decode` (observability only —
      paint logic unchanged for backward-compat) so the harness
      summary JSON now carries `newest_frame_wins.{accepted,
      stale_dropped, duplicate_dropped, last_accepted_seq}`. The S3
      gate target is `stale_dropped == 0` over a 10-minute mixed-load
      run — pre-validation today, validation blocked on the L072
      reattach + W2-02 stability rig.)*
- [x] **S1.4** ✅ *(CLOSED 2026-05-19 — full sweep + soak both landed)*
      Commit one full `walk_power` sweep and one 10-minute mixed-load run
      to `bench-evidence/`.
      *(Pilot 2026-05-19: 16-step × 50-packet paired sweep at
      `DESIGN-CONTROLLER/bench-evidence/walk_power_pilot_2026-05-19/` —
      verdict OK, mean PER 0.59 %, RSSI/SNR monotonic.
      Full 2026-05-19: 16-step × 200-packet paired sweep at
      `DESIGN-CONTROLLER/bench-evidence/walk_power_full_2026-05-19/` —
      verdict OK, mean PER 1.22 %, 3 200/3 200 `tx_done_ok`,
      0 `tx_aborted_airtime` at `--inter-cycle-s 0.07`, RSSI -118.9 →
      -111.2 dBm monotonic.
      Soak 2026-05-19: 6 500-packet × ~13 min paired soak at
      `DESIGN-CONTROLLER/bench-evidence/mixed_load_2026-05-19/` —
      6 500/6 500 `tx_done_ok`, 0 timeout, **0 faults, 0 invariants
      violated**, 6 463/6 500 RX (PER 0.57 %).
      Airtime-gate falsification done: the pilot's 12-16 % attempt loss was
      NOT EU 1 % regulatory but the 40 % internal per-channel fairness cap
      in `sx1276_airtime.c`; see
      `AI NOTES/2026-05-19_FCC_Part15_902-928_Compliance_Notes_Copilot_v1_0.md`
      for the actual FCC envelope and the resulting FHSS work item.
      Multi-channel / multi-payload-class "mixed-load" is gated on FHSS
      scheduler landing — captured as a follow-up in the mixed_load README.)*
- **Gate:** measured vs. predicted encrypted ToA delta < 10 ms on at least
  one P0 and one P3 packet class. (S1.0 unit tests against historical CSVs
  give a software-only proxy that can pre-pass before LoRa rig returns.)

### Stage S1.5 — FCC §15.247 50-channel FHSS (PRE-LAUNCH BLOCKER) 🔴 NEW
*(Per [AI NOTES/2026-05-19_FCC_Part15_902-928_Compliance_Notes_Copilot_v1_0.md](AI%20NOTES/2026-05-19_FCC_Part15_902-928_Compliance_Notes_Copilot_v1_0.md)
§19-§20 and the v3.0 consolidated execution order in
[AI NOTES/2026-05-19_LoRa_FCC_50CH_FHSS_Implementation_Plan_Copilot_v1_0.md §14](AI%20NOTES/2026-05-19_LoRa_FCC_50CH_FHSS_Implementation_Plan_Copilot_v1_0.md#14-consolidated-v30-plan-deltas-authoritative).
Production radio profile is `FCC_15_247_FHSS_50CH_BW250` at the existing
+17 dBm clamp. All current S1.x bench evidence is stamped
`BENCH_ONLY_FIXED_915` and is **not** FCC field evidence. The L072 today
hardcodes `s_channel_idx = 0U` in `sx1276_tx.c:64` — single fixed
channel — which is the single largest compliance gap.)*

**Implementation (firmware, executed in v3.0 order):**
- [x] **FCC-FHSS-CHANTAB** ✅ *(2026-05-19 — landed)* Channel-table
      generator + static asserts:
      `_Static_assert(FHSS_CHANNEL_COUNT == 50)`,
      `_Static_assert(FHSS_CHANNEL_SPACING_HZ >= 25000)`,
      first/last centers asserted inside 902-928 MHz. Formula
      `center_hz = 902_750_000 + 500_000*i, i=0..49` (span 902.750-927.250
      MHz, 750 kHz edge guard). Files:
      [`include/sx1276_fhss_chantab.h`](DESIGN-CONTROLLER/firmware/murata_l072/include/sx1276_fhss_chantab.h),
      [`radio/sx1276_fhss_chantab.c`](DESIGN-CONTROLLER/firmware/murata_l072/radio/sx1276_fhss_chantab.c),
      golden-vector C test
      [`bench/host_proto/fhss_chantab_vectors.c`](DESIGN-CONTROLLER/firmware/murata_l072/bench/host_proto/fhss_chantab_vectors.c),
      Python mirror (X8-side parity, byte-identical golden vectors)
      [`bench/host_proto/fhss_chantab.py`](DESIGN-CONTROLLER/firmware/murata_l072/bench/host_proto/fhss_chantab.py).
      Wired into Makefile via new `check-fhss-chantab` target hooked
      into the aggregate `check`. Verified: `mingw32-make check` passes
      with `[OK] sx1276_fhss_chantab: all checks passed (count=50,
      span=902750000..927250000 Hz)`.
      Final spacing tighten is gated on FCC-EVID-D2 (measured 20 dB
      OBW); placeholder comment in the .c file marks the future assert.
- [x] **FCC-PROFILE-ENUM** ✅ *(2026-05-19 — landed)* Added
      `CFG_KEY_REG_PROFILE` (key `0x14U`, u8) with enum
      `{REG_PROFILE_BENCH_ONLY_FIXED_915=0,
      REG_PROFILE_FCC_15_247_FHSS_50CH_BW250=1,
      REG_PROFILE_FCC_15_247_DTS_BW500=2}` in
      [`include/host_cfg_keys.h`](DESIGN-CONTROLLER/firmware/murata_l072/include/host_cfg_keys.h).
      New status code `CFG_STATUS_PROFILE_UNROUTED=7` in
      [`include/host_cfg.h`](DESIGN-CONTROLLER/firmware/murata_l072/include/host_cfg.h).
      Validator in
      [`host/host_cfg.c`](DESIGN-CONTROLLER/firmware/murata_l072/host/host_cfg.c)
      always accepts bench profile, rejects unknown values with
      `OUT_OF_RANGE`, gates both production profiles behind
      `#ifdef LIFETRAC_FHSS_TX_ROUTED` (undefined until FCC-A4) →
      returns `CFG_STATUS_PROFILE_UNROUTED` today. Default value =
      bench profile. `CFG_KEY_COUNT` bumped 20→21;
      `HOST_WIRE_SCHEMA_VER` bumped 1→2. Tests in
      [`bench/host_proto/cfg_contract.c`](DESIGN-CONTROLLER/firmware/murata_l072/bench/host_proto/cfg_contract.c)
      extended with 4 cases (`reg_profile_bench_default_ok`,
      `reg_profile_fcc_fhss_unrouted`, `reg_profile_fcc_dts_unrouted`,
      `reg_profile_unknown_oor`). `mingw32-make check-cfg-contract`
      passes 34 cases + 6 wire vectors.
- [x] **FCC-A1a** Config-time airtime invariant in modem-config setter:
      reject `(SF, BW, CR)` whose worst-case ToA > `dwell_cap_ms - guard_ms`
      (400 - 20 ms default). New URC `__AIRTIME_INVARIANT_REJECT__`.
      ✅ 2026-05-19. New pure helper `sx1276_airtime_compute_toa_us()`
      and config-time predicate `sx1276_airtime_config_invariant_ok()`
      added in
      [`include/sx1276_airtime.h`](DESIGN-CONTROLLER/firmware/murata_l072/include/sx1276_airtime.h)
      /
      [`radio/sx1276_airtime.c`](DESIGN-CONTROLLER/firmware/murata_l072/radio/sx1276_airtime.c);
      cap constants `SX1276_AIRTIME_DWELL_WINDOW_MS=400`,
      `SX1276_AIRTIME_DWELL_GUARD_US=20000`,
      `SX1276_AIRTIME_DWELL_CAP_US=380000`. New URC byte
      `HOST_TYPE_AIRTIME_INVARIANT_REJECT_URC=0xC2` with 15-byte payload
      `{u8 sf, u8 cr_den, u32 bw_hz_le, u8 payload_len, u32 toa_us_le, u32 cap_us_le}`
      registered in
      [`include/host_types.h`](DESIGN-CONTROLLER/firmware/murata_l072/include/host_types.h)
      (added to compile-time uniqueness switch). New bool-returning
      variant `sx1276_set_sf_bw_cr_checked()` in
      [`radio/sx1276.c`](DESIGN-CONTROLLER/firmware/murata_l072/radio/sx1276.c)
      runs the invariant at max payload (255 B); on reject it emits the
      URC and skips all modem-register writes so the prior legal config
      is retained. The existing `void sx1276_set_sf_bw_cr()` is kept as
      a thin wrapper that discards the bool to preserve all existing
      call sites (init path: SF7/BW250/CR45 → 199.808 ms, accepted).
      Host golden vectors in
      [`bench/host_proto/airtime_invariant.c`](DESIGN-CONTROLLER/firmware/murata_l072/bench/host_proto/airtime_invariant.c)
      (7 cases incl. SF12/BW125/255B reject, SF11/BW125/255B reject,
      SF10/BW500/255B reject, SF7/BW250/255B accept, SF7/BW250/24B
      accept). `mingw32-make check-airtime-invariant` →
      `[PASS] airtime_invariant: 7 cases`; aggregate
      `mingw32-make check` still green
      (`[OK] sx1276_fhss_chantab` + `[PASS] airtime_invariant` +
      `[OK] memory map invariants hold`).
- [x] **FCC-A1b** Pre-TX airtime invariant in `sx1276_tx_begin()` keyed on
      actual payload + header + CRC + preamble + safety-burst framing.
      Host-side mirror calc keyed on `profile_id` so oversized payloads
      never reach the L072.
      ✅ 2026-05-19. Per-frame dwell-cap check added in
      [`radio/sx1276_tx.c`](DESIGN-CONTROLLER/firmware/murata_l072/radio/sx1276_tx.c)
      between LBT and `sx1276_airtime_reserve()`: calls
      `sx1276_airtime_estimate_toa_us(req->length)` (which reads live
      modem-config + preamble registers), and on `predicted > 380 ms`
      increments `host_stats_radio_tx_abort_airtime()`, runs
      `sx1276_tx_cleanup()` (re-arms RX if needed), and returns false.
      Counter-ownership check (`[OK] Airtime abort ownership check passed`)
      confirms the increment site is still uniquely owned by
      `radio/sx1276_tx.c`. Host-side mirror table + lookup added in
      [`bench/host_proto/airtime_invariant.c`](DESIGN-CONTROLLER/firmware/murata_l072/bench/host_proto/airtime_invariant.c)
      mapping `REG_PROFILE_BENCH_ONLY_FIXED_915`,
      `REG_PROFILE_FCC_15_247_FHSS_50CH_BW250`,
      `REG_PROFILE_FCC_15_247_DTS_BW500` to their `(sf, bw_khz, cr_den)`
      tuples (table is FCC-A4's production-routing precursor). Five new
      test cases prove: (a) every payload 0..255 is accepted under the
      FHSS profile, (b) ToA is monotonic non-decreasing in payload_len,
      (c) host mirror agrees byte-for-byte with the on-target helper at
      payloads {0,1,16,24,64,128,200,255}, (d) bench profile @255B fits
      under cap, (e) unknown `profile_id` fails closed without mutating
      the out param. `mingw32-make check-airtime-invariant` →
      `[PASS] airtime_invariant: 12 cases`; aggregate `mingw32-make check`
      still green; `mingw32-make check-airtime-counter-owner` still
      `[OK]`.
- [x] **FCC-A3** New `radio/sx1276_fhss.{c,h}`: 50-channel table, pseudo-
      random permutation `permute(H(farm_id||node_id||epoch))`, blacklist
      with legal floor (refuse if active set would drop below 50),
      cold-start warm-up, `record_lbt_block()` separate from blacklist.
      **Fails closed** on invalid epoch / hop / timebase. Golden vectors
      checked in under `bench/host_proto/`.
      ✅ 2026-05-19. New module landed:
      [`include/sx1276_fhss.h`](DESIGN-CONTROLLER/firmware/murata_l072/include/sx1276_fhss.h)
      defines the `sx1276_fhss_status_t` fail-closed enum
      (`NOT_INIT`/`NULL_ARG`/`BAD_IDX`/`BLACKLIST_FLOOR`/`BLACKLIST_WARMUP`/`ALREADY_BLACKED`/`INTERNAL`)
      plus pure helpers `sx1276_fhss_compute_seed()` (FNV-1a 32-bit over
      LE `farm_id||node_id||epoch`) and `sx1276_fhss_compute_permutation()`
      (Fisher-Yates seeded by xorshift32; zero-seed fallback prevents
      the xorshift32 zero-state trap).
      [`radio/sx1276_fhss.c`](DESIGN-CONTROLLER/firmware/murata_l072/radio/sx1276_fhss.c)
      implements the stateful scheduler with `init/reset/next_channel/
      epoch_advance/blacklist/active_count/record_lbt_block/lbt_block_count`
      plus `current_epoch/slot/seed/is_initialized` telemetry getters.
      Cold-start warm-up = 50 hops (`SX1276_FHSS_WARMUP_HOPS`);
      `_Static_assert` enforces legal floor ≤ channel count and channel
      count ≤ 64 (blacklist bitmap fits `uint64_t`). Time source NOT read
      inside the module — caller drives `epoch_advance()` from the
      monotonic tick so golden vectors stay deterministic. New
      `mingw32-make check-fhss-scheduler` target →
      `[PASS] fhss_scheduler_vectors: 11 cases` covering: 3 hard-coded
      golden seed+permutation vectors (zero / nominal /
      `0xFFFF…F`-saturated), determinism vs distinctness, zero-seed
      fallback, NOT_INIT / NULL_ARG / BAD_IDX fail-closed paths,
      single-epoch coverage bijection, slot-wrap auto-advance, warm-up
      blacklist refusal then post-warm-up floor refusal, LBT-block
      decoupling, and epoch-advance regeneration. Aggregate
      `mingw32-make check` still green
      (`[OK] sx1276_fhss_chantab` + `[PASS] fhss_scheduler_vectors: 11 cases`
      + `[PASS] airtime_invariant: 12 cases` + `[OK] memory map invariants
      hold`). Host mirror at `bench/host_proto/fhss_scheduler.py` is
      deferred to FCC-A4 (when X8-side hop prediction lands).
- [x] **FCC-A2** ✅ 2026-05-19 — split addressed by **adding** a new
      module rather than carving the existing one: the 1 s / 400 ms QoS
      gate stays untouched in
      [`radio/sx1276_airtime.c`](DESIGN-CONTROLLER/firmware/murata_l072/radio/sx1276_airtime.c)
      (still emitting `qos_used_us_1s`); the FCC §15.247(a)(1)(i)
      legal-dwell accountant lives in
      [`include/sx1276_legal_dwell.h`](DESIGN-CONTROLLER/firmware/murata_l072/include/sx1276_legal_dwell.h)
      + [`radio/sx1276_legal_dwell.c`](DESIGN-CONTROLLER/firmware/murata_l072/radio/sx1276_legal_dwell.c).
      Widened to 64 channel slots (`SX1276_DWELL_CHANNEL_COUNT=64`);
      both 10 s (`legal_dwell_used_us_10s`) and 20 s
      (`legal_dwell_used_us_20s`) windows supported via a `window_ms`
      parameter (the 20 s variant is gated on by FCC-A5 cfg validation,
      not by this module). Window semantics are half-open `[t-W, t)`
      (event at `start_ms == now - W` is OUT; tested at
      [`bench/host_proto/legal_dwell.c` L116-L131](DESIGN-CONTROLLER/firmware/murata_l072/bench/host_proto/legal_dwell.c#L116-L131)).
      Storage model: single shared 128-event ring carrying per-event
      channel index (~1.5 KiB RAM) — chosen over per-channel mini-rings
      to fit L072's 20 KiB SRAM. Pessimistic reserve immediately books
      the worst-case ToA; reconcile is **monotonically downward only**
      (cannot grow legal dwell beyond the reservation, verified by
      [`test_reconcile_up_is_noop`](DESIGN-CONTROLLER/firmware/murata_l072/bench/host_proto/legal_dwell.c#L91-L102)).
      No-rollback-on-NACK contract is enforced **structurally** by not
      exposing any release API; verified by
      [`test_no_rollback_on_nack`](DESIGN-CONTROLLER/firmware/murata_l072/bench/host_proto/legal_dwell.c#L104-L121)
      which proves the booking persists for the entire window after a
      simulated NACK. Property tests also cover per-channel isolation,
      64-ch widening + `BAD_CH`, 10 s vs 20 s window split, over-budget
      rejection (does not book), ring-full fail-closed, stale-handle
      generation safety, and bad-input rejection. Wired into
      [`Makefile`](DESIGN-CONTROLLER/firmware/murata_l072/Makefile) as
      `check-legal-dwell` and the aggregate `check` target. Last run
      green: `mingw32-make check` →
      `[OK] sx1276_fhss_chantab` + `[PASS] fhss_scheduler_vectors: 11 cases`
      + `[PASS] airtime_invariant: 12 cases` +
      `[PASS] legal_dwell: 15 cases` + `[OK] memory map invariants hold`.
      Integration into `sx1276_tx.c` (calling `reserve()` before
      LBT/TX-start and `reconcile()` from TX-done) is part of FCC-A4
      (active-set wiring) so the module stays unused but verified
      until then.
- [x] **FCC-B1-PERTX** ✅ 2026-05-19 — Per-TX `RFCO` URC scaffolded.
      URC type `HOST_TYPE_RFCO_PERTX_URC = 0xC3U` registered in
      [`include/host_types.h`](DESIGN-CONTROLLER/firmware/murata_l072/include/host_types.h)
      with cross-ref to the full spec in
      [`include/host_rfco.h`](DESIGN-CONTROLLER/firmware/murata_l072/include/host_rfco.h).
      Payload is 21 bytes, little-endian, schema_ver=1, additive-only:
      `{schema_ver, profile_id, tx_status, hop_idx, channel_idx, epoch,
      freq_hz, pkt_toa_us, legal_dwell_used_us_10s}`. Naming discipline
      per plan delta #11 — the dwell field is explicitly suffixed
      `_us_10s` so bench post-processing can never conflate it with
      `qos_used_us_1s`. Status enum covers OK / ABORT_* (one per fail-
      closed gate: airtime invariant, LBT, legal-dwell, QoS) / TX_TIMEOUT
      / TX_FAIL / INTERNAL. Pack + emit live in
      [`host/host_rfco.c`](DESIGN-CONTROLLER/firmware/murata_l072/host/host_rfco.c)
      — pack() is pure (host-testable, no HAL deps) and emit() is the
      ONLY public wrapper around `host_uart_send_urc()` for this URC so
      the schema_ver byte stays in one place. Host test
      [`bench/host_proto/rfco_pertx.c`](DESIGN-CONTROLLER/firmware/murata_l072/bench/host_proto/rfco_pertx.c)
      pins the wire layout with a byte-for-byte golden vector
      (`freq_hz=915500000=0x36916BE0`, `pkt_toa_us=12345`,
      `legal_dwell_used_us_10s=200000`), edge-value coverage
      (UINT32_MAX in all u32 fields, status=0xFF round-trip), NULL-input
      rejection, and a forwarding test that verifies emit() calls
      `host_uart_send_urc` with `(type=0xC3, payload_len=21, payload ==
      pack(snapshot))`. Wired into
      [`Makefile`](DESIGN-CONTROLLER/firmware/murata_l072/Makefile) as
      `check-rfco-pertx` and the aggregate `check` target. Last run
      green: `mingw32-make check` →
      `[OK] sx1276_fhss_chantab` + `[PASS] fhss_scheduler_vectors: 11 cases`
      + `[PASS] airtime_invariant: 12 cases` +
      `[PASS] legal_dwell: 15 cases` +
      `[PASS] rfco_pertx: 6 cases` + `[OK] memory map invariants hold`.
      `host/host_rfco.c` is in the firmware SRCS list so it will link
      into the next cross-build; the call site in `sx1276_tx.c`
      (emitting OK / ABORT_* / TX_FAIL) is deferred to FCC-A4 when TX
      is routed through the FHSS scheduler — until then there is no
      `channel_idx` / `epoch` to report, so emitting now would supply
      stub zeros and pollute bench evidence. The 50-bucket per-channel
      histogram + per-channel `legal_dwell_max_us` snapshot is the
      separate per-minute `RFCO_SUMMARY` URC (FCC-B1-SUMMARY).
- [x] **FCC-A5** ✅ 2026-05-19 — Regulatory-profile validator + two-phase
      commit landed as pure, host-testable module
      [`include/host_cfg_profile.h`](DESIGN-CONTROLLER/firmware/murata_l072/include/host_cfg_profile.h)
      / [`host/host_cfg_profile.c`](DESIGN-CONTROLLER/firmware/murata_l072/host/host_cfg_profile.c).
      State machine is `host_cfg_profile_reset(initial)` →
      `host_cfg_profile_stage(&req, tx_routed)` →
      `host_cfg_profile_activate()` with `host_cfg_profile_cancel_stage()`
      and `host_cfg_profile_has_stage()` introspection. Active profile
      is NEVER mutated on a failed stage or a failed activate
      (NOT_STAGED). A failed stage clears any prior in-flight stage so a
      stale candidate cannot accidentally commit on the next activate.
      Validator enforces (per plan §A5):
        - `popcount(channel_mask) >= 50` for `FCC_15_247_FHSS_50CH_BW250`
          (since the certified table is exactly 50 bits this collapses
          to `channel_mask == HOST_CFG_PROFILE_FHSS_50CH_REQUIRED_MASK
          = (1ULL<<50)-1`),
        - no mask bits set above bit 49 (table-membership),
        - modem BW == 250 kHz for FHSS / 500 kHz for DTS,
        - antenna gain ∈ [0, 30] dBi,
        - production profiles are rejected with `REJECT_UNROUTED` when
          the explicit `tx_routed` boolean (mirroring compile-time
          `LIFETRAC_FHSS_TX_ROUTED`) is false. Until FCC-A4 lands the
          firmware passes `tx_routed = false` so only
          `BENCH_ONLY_FIXED_915` activates.
      Profile-aware power clamp is the pure helper
      `host_cfg_profile_power_clamp(tier_ceiling, hw_ceiling, gain)`
      implementing `Pmax = min(tier_ceiling - max(0, gain_dBi - 6),
      hw_ceiling)` floored at `HOST_CFG_PROFILE_TX_POWER_MIN_DBM = 2`;
      returns 0 when no headroom remains and the validator maps that to
      `REJECT_NO_POWER_HEADROOM`. Tier ceilings: bench = +17 dBm (hw
      ceiling), FHSS = +30 dBm tier, DTS = +30 dBm tier; production
      tiers are then further clamped by the caller-supplied
      `hw_ceiling_dBm` (typically +17/+20 dBm on this Murata module).
      Structured reject reasons (`HOST_CFG_PROFILE_REJECT_*`,
      BAD_PROFILE / MASK_POPCOUNT / MASK_OUT_OF_TABLE / BW_MISMATCH /
      ANTENNA_OUT_OF_RANGE / NO_POWER_HEADROOM / UNROUTED / NOT_STAGED
      / NULL_ARG) are surfaced byte-for-byte to the wire layer so bench
      post-processing can attribute every rejection. Host test
      [`bench/host_proto/cfg_profile.c`](DESIGN-CONTROLLER/firmware/murata_l072/bench/host_proto/cfg_profile.c)
      runs 25 cases covering the validator (every reject reason),
      power-clamp arithmetic (gain≤6 no-op, gain>6 ERP reduction,
      hw-ceiling clamp, negative gain, no-headroom floor), tier-ceiling
      lookup, and the full state machine (happy path, activate-without-
      stage, failed-stage-clears-in-flight, cancel, double-activate,
      unrouted-leaves-active-alone). Wired into
      [`Makefile`](DESIGN-CONTROLLER/firmware/murata_l072/Makefile) as
      `check-cfg-profile` and the aggregate `check` target; module is
      also in firmware SRCS so the next cross-build will link it.
      `cfg_set(CFG_KEY_REG_PROFILE)` integration (routing wire-level
      profile writes through stage/activate) is deferred to FCC-A4 when
      `LIFETRAC_FHSS_TX_ROUTED` is defined and there is a routed TX
      path to honour the new profile. Last run green: `mingw32-make
      check` → `[OK] chantab` + `[PASS] fhss_scheduler_vectors: 11
      cases` + `[PASS] airtime_invariant: 12 cases` +
      `[PASS] legal_dwell: 15 cases` + `[PASS] rfco_pertx: 6 cases` +
      `[PASS] cfg_profile: 25 cases` + `[OK] memory map invariants
      hold`.
- [x] **FCC-A4** Replace `s_channel_idx = 0U` in
      [`sx1276_tx.c` L64](DESIGN-CONTROLLER/firmware/murata_l072/radio/sx1276_tx.c)
      with `sx1276_fhss_next_channel()` + `sx1276_set_frequency_hz()` +
      PLL settle (document measured settle budget) **before** LBT/CAD/TX-
      start. Defines `LIFETRAC_FHSS_TX_ROUTED`.
      Landed 2026-05-19 (assistant): the FHSS-routed TX path is gated
      by `#ifdef LIFETRAC_FHSS_TX_ROUTED` in
      [`radio/sx1276_tx.c`](DESIGN-CONTROLLER/firmware/murata_l072/radio/sx1276_tx.c).
      On `sx1276_tx_begin()` the new flow is: capture `(hop_idx,
      epoch, channel_idx, freq_hz)` from
      `sx1276_fhss_next_channel()` → modes_to_standby → retune via
      `sx1276_set_frequency_hz(freq_hz)` → busy-wait
      `SX1276_TX_PLL_SETTLE_US=200 µs` (4× the SX1276 datasheet rev 7
      §4.1.4 ~50 µs worst-case PLL lock budget; pending bench
      characterisation under the actual Murata CMWX1ZZABZ TCXO) → LBT
      → FCC-A1b airtime invariant → FCC-A2
      `sx1276_legal_dwell_reserve(channel_idx, predicted_toa_us,
      now_ms, 10_000 ms, 400_000 µs)` → QoS reserve → FIFO →
      `modes_to_tx()`. Every fail-closed gate (INTERNAL, ABORT_LBT,
      ABORT_AIRTIME_INVARIANT, ABORT_QOS, ABORT_LEGAL_DWELL, TX_FAIL)
      emits an `RFCO_PERTX` URC via `tx_emit_rfco_pertx()` so bench
      post-processing sees the captured hop state regardless of
      outcome. `sx1276_tx_poll()` reconciles the legal-dwell reserve
      down to the post-rearm predicted ToA on TX_DONE and emits
      `HOST_RFCO_TX_STATUS_OK`; on timeout it emits
      `HOST_RFCO_TX_STATUS_TX_TIMEOUT` and leaves the pessimistic
      reserve booked (FCC-A2 no-rollback contract). The pre-A4
      fixed-channel behaviour is preserved when
      `LIFETRAC_FHSS_TX_ROUTED` is undefined (host test builds), so
      the existing `cfg_contract` tests that lock in
      `CFG_STATUS_PROFILE_UNROUTED` continue to pass. The build
      symbol is now added to firmware-only `CFLAGS` in
      [`Makefile`](DESIGN-CONTROLLER/firmware/murata_l072/Makefile),
      which automatically unlocks the production profile in
      `host_cfg.c` (`cfg_set(CFG_KEY_REG_PROFILE,
      FCC_15_247_FHSS_50CH_BW250)` now returns `CFG_STATUS_OK` on
      firmware builds). Evidence: `mingw32-make check` →
      `[OK] sx1276_fhss_chantab: count=50, span=902750000..927250000
      Hz` + `[PASS] fhss_scheduler_vectors: 11 cases` +
      `[PASS] airtime_invariant: 12 cases` +
      `[PASS] legal_dwell: 15 cases` + `[PASS] rfco_pertx: 6 cases` +
      `[PASS] cfg_profile: 25 cases` + `[OK] memory map invariants
      hold`. `gcc -fsyntax-only -DLIFETRAC_FHSS_TX_ROUTED=1` and
      without the flag both produce zero diagnostics on
      `radio/sx1276_tx.c`. Follow-on `cfg_set(REG_PROFILE)` →
      `host_cfg_profile_stage/activate` integration and full
      cross-toolchain link verification deferred to Phase D bench
      bring-up (no `arm-none-eabi-gcc` on this host).
- [ ] **FCC-A6** RX hop sync: same `permute(seed, epoch)`; packet header
      carries authenticated `{profile_id, epoch, hop_idx, schema_ver}`.
      Explicit **Scanning** state for cold start — wideband scan across
      active set, **no fixed rendezvous channel**.
    - [x] **FCC-A6a** LoRa link-layer packet header pack/unpack
          contract — `include/lora_pkt_hdr.h` + `radio/lora_pkt_hdr.c`.
          8-byte v1 layout: `{schema_ver:u8, profile_id:u8, hop_idx:u8,
          _reserved:u8, epoch_le:u32}`. MIC trailer is reserved for a
          future additive `schema_ver=2` (FCC notes §17.3 #4); no MIC
          today because Track-C1 LoRa-link MIC/AEAD is unblocked but
          not yet implemented (plan §7 Q4, deferred). Parser refuses
          unknown schema_ver and leaves `*out` untouched on every
          failure path. Reserved byte is intentionally ignored on
          parse to keep the schema additive-evolution friendly.
          Evidence: `mingw32-make check` →
          `[PASS] lora_pkt_hdr: 10 cases` (constants, nominal golden,
          all-zero golden, edge values, NULL/short/bad-schema
          rejection, round-trip, reserved-byte ignore) plus all 6
          prior tests still green and
          `[OK] memory map invariants hold`. Not yet wired into
          `sx1276_tx.c` (prepend) or `sx1276_rx.c` (strip) — that
          wiring belongs to A6b/A6c so the header schema can be
          frozen and consumed unchanged once RX retune lands.
    - [ ] **FCC-A6b** RX tune-to-hop integration in `radio/sx1276_rx.c`
          + `sx1276_fhss`: derive the same `permute(seed, epoch)` as
          TX, retune between RX windows from `host_fhss_next_channel`,
          align epoch from `platform_now_ms()` monotonic tick, prepend
          A6a header to every TX in `sx1276_tx.c` (gated on
          `LIFETRAC_FHSS_TX_ROUTED`), and consume it in the RX
          service path to confirm or correct the local hop pointer.
        - [x] **FCC-A6b-1** Header prepend/strip cutover —
              `radio/sx1276_tx.c` prepends the 8-byte A6a header to
              every FIFO write under `LIFETRAC_FHSS_TX_ROUTED`, with a
              pre-FHSS overflow guard (`req->length + LORA_PKT_HDR_LEN
              > 255` ⇒ emit `RFCO TX_STATUS_INTERNAL` and bail before
              consuming a hop slot). All length-bearing downstream
              calls (`sx1276_airtime_estimate_toa_us`,
              `sx1276_airtime_reserve`, fallback ToA estimate, FIFO
              `PAYLOAD_LENGTH`) now use the on-air `effective_len`
              including header; the `req->payload` FIFO burst stays at
              `req->length`. `radio/sx1276_rx.c` strips the leading 8
              bytes after RX_DONE, parses via `lora_pkt_hdr_unpack`,
              populates `out_frame->hdr` + `hdr_valid`, slides
              remaining bytes forward, and drops frames with
              short/bad-schema headers (IRQ still acked; visibility
              deferred to FCC-B1-SUMMARY rather than a host_stats
              wire-layout bump). `sx1276_rx_frame_t` extended with
              `lora_pkt_hdr_t hdr` + `bool hdr_valid` (struct always
              carries the fields; `hdr_valid==false` when unrouted).
              Behavior with `LIFETRAC_FHSS_TX_ROUTED` undefined is
              byte-for-byte identical to before. Evidence:
              `mingw32-make check` → all 7 host tests still green +
              `[OK] memory map invariants hold`; `gcc -fsyntax-only`
              clean on `radio/sx1276_tx.c` + `radio/sx1276_rx.c` both
              with and without the flag.
        - [ ] **FCC-A6b-2** RX retune loop — between RX windows,
              consume `sx1276_fhss_next_channel` and call
              `sx1276_set_frequency_hz` + PLL settle so the receiver
              follows the same hopset as TX. On a `hdr_valid` frame
              whose `(epoch, hop_idx)` disagrees with the local
              scheduler, snap the local pointer (define the snap
              policy — e.g., only when |Δepoch| ≤ 1 and within a guard
              slot, to refuse spoofed jumps once a MIC ships).
              Resync slot policy: reserve one slot per epoch where RX
              parks for a known seed-slot dwell as a fallback if N
              consecutive epochs decode-fail.
            - [x] **FCC-A6b-2-i** Scheduler snap primitive —
                  `sx1276_fhss_snap_to(target_epoch, snap_to_slot)` in
                  `include/sx1276_fhss.h` + `radio/sx1276_fhss.c`.
                  Atomically sets `(epoch, slot)`, rebuilds the
                  permutation from `H(farm_id, node_id, target_epoch)`,
                  clears `warmup_hops_remaining` (snapping implies the
                  remote is past warm-up), preserves `blacklist_bits`
                  and `lbt_block_count[]` (per-channel quality history
                  survives). `snap_to_slot == CHANNEL_COUNT` is legal
                  and lets the next `next_channel()` trip the wrap
                  path. Fails closed on `NOT_INIT` and
                  `snap_to_slot > CHANNEL_COUNT` (`BAD_IDX`) without
                  mutating state. The policy layer
                  (`consider_remote(epoch, hop_idx)` deciding when to
                  call snap_to vs. ignore the remote hint) and the
                  RX-side wire-up will land with A6b-2-ii where they
                  have a caller. Evidence: `mingw32-make check` →
                  `[PASS] fhss_scheduler_vectors: 16 cases` (was 11;
                  5 new: fails-closed, lands-on-expected-slot,
                  slot==CHANNEL_COUNT wrap, clears-warmup,
                  preserves-quality-history) plus all other host tests
                  still green + `[OK] memory map invariants hold`.
            - [ ] **FCC-A6b-2-ii** RX retune loop + snap-policy layer —
                  introduce `sx1276_fhss_consider_remote(epoch,
                  hop_idx)` deciding ALIGNED / SNAPPED / REJECTED based
                  on `|Δepoch| ≤ 1` (until MIC ships), call it from
                  `sx1276_rx_service` on `hdr_valid` frames, add an
                  `sx1276_rx_tick(now_ms)` API that the main loop
                  drives so RX retunes between windows via
                  `sx1276_fhss_next_channel` + `sx1276_set_frequency_hz`
                  + PLL settle. Window duration is gated on the
                  epoch-model decision in plan §7 open Q2.
                - [x] **FCC-A6b-2-ii-α** Snap-policy primitive —
                      `sx1276_fhss_consider_remote(remote_epoch,
                      remote_hop_idx) →
                      sx1276_fhss_snap_decision_t { ALIGNED, SNAPPED,
                      REJECTED_NOT_INIT, REJECTED_BAD_HOP,
                      REJECTED_EPOCH_DRIFT }` in
                      `include/sx1276_fhss.h` + `radio/sx1276_fhss.c`.
                      ALIGNED uses the same local_hop_idx convention
                      as sx1276_tx.c stamping (slot==0 ? N-1 :
                      slot-1) — symmetric with TX so genuine
                      lock-step peers no-op. SNAPPED gate is
                      `|Δepoch| ≤ SX1276_FHSS_SNAP_MAX_EPOCH_DRIFT
                      (=1)` computed via `(int32_t)(remote-local)`
                      (uint32 wrap-safe across the 0xFFFFFFFF→0
                      boundary). On SNAPPED, `snap_to(remote_epoch,
                      remote_hop_idx + 1)` is called internally (the
                      slot the remote will emit next; +1 ==
                      CHANNEL_COUNT wrap handled by snap_to's spec).
                      All REJECTED_* paths are no-ops. Has no caller
                      yet — the RX wire-up lands with -β and -γ where
                      the call site exists. Evidence: `mingw32-make
                      check` → `[PASS] fhss_scheduler_vectors: 23
                      cases` (was 16; 7 new: fails-closed,
                      aligned-no-op, snapped-same-epoch,
                      snapped-±1-epoch-drift, rejected-drift-incl-far-
                      replay, uint32-wrap-boundary, snapped-wrap-slot)
                      plus all other host tests green +
                      `[OK] memory map invariants hold`.
                - [x] **FCC-A6b-2-ii-β** RX call-site wire-up — call
                      `sx1276_fhss_consider_remote(parsed.epoch,
                      parsed.hop_idx)` from `sx1276_rx_service`
                      immediately after a successful
                      `lora_pkt_hdr_unpack` (i.e., when `hdr_valid` is
                      set). The returned decision is fed to
                      `sx1276_rx_counter_record(dec)` which lives in a
                      HW-free TU (`radio/sx1276_rx_counters.c`,
                      extracted so the saturating-increment +
                      snapshot/reset semantics are host-testable
                      without dragging in modem deps). Counters are
                      indexed by `sx1276_fhss_snap_decision_t`
                      (ALIGNED / SNAPPED / REJECTED_NOT_INIT /
                      REJECTED_BAD_HOP / REJECTED_EPOCH_DRIFT, dim=5),
                      saturate at `UINT32_MAX`, and are exposed via
                      `sx1276_rx_consider_remote_counts(out[5])` +
                      `_reset()`. **REJECTED_* outcomes do NOT drop
                      the frame** — the payload is still useful even
                      if the snap was refused (drift-flag is purely
                      diagnostic until A6 MIC ships). No `host_stats`
                      field added (no host↔X8 wire layout bump);
                      FCC-B1-SUMMARY will surface these via an
                      additive URC. Evidence: `mingw32-make check` →
                      `[PASS] rx_counters: 10 cases` (initial-zero,
                      per-slot-isolation, out-of-range no-op,
                      snapshot-idempotency, reset-round-trip,
                      NULL-arg safety, no-narrow-type-wrap @ 4096
                      records, interleaved-accumulation, DIM-matches-
                      enum invariant, post-reset-usable) + all 7
                      previous host tests still green + `[OK] memory
                      map invariants hold` + `gcc -fsyntax-only` clean
                      on `sx1276_rx.c` + `sx1276_rx_counters.c` +
                      `sx1276_tx.c` both with and without
                      `-DLIFETRAC_FHSS_TX_ROUTED=1`.
                - [ ] **FCC-A6b-2-ii-γ** RX retune loop + `rx_tick` —
                      add `sx1276_rx_tick(now_ms)` API the main loop
                      drives; between RX windows, advance the scheduler
                      via `sx1276_fhss_next_channel` and apply
                      `sx1276_set_frequency_hz` + PLL settle so the
                      receiver follows the same hopset as TX. Window
                      duration gated on plan §7 open Q2 epoch-model
                      decision. **Split** (same playbook as A6b-2-ii-α/β
                      — pure-function policy first, HW mechanism second,
                      Q2-dependent final policy third):
                    - [x] **FCC-A6b-2-ii-γ-1** Retune-decision pure
                          function — HW-free TU
                          `radio/sx1276_rx_retune_policy.c` exposing
                          `sx1276_rx_retune_eval(now_ms,
                          last_retune_ms, modem_busy, fhss_ready)
                          → enum { DO=0, SKIP_NOT_INIT=1,
                          SKIP_BUSY=2, SKIP_TOO_SOON=3, DO_WRAP=4 }`.
                          Window-duration constant
                          `SX1276_RX_RETUNE_PERIOD_MS = 380U` (≤ FCC
                          dwell cap so it is never illegal regardless
                          of which Q2 model wins) — γ-3 swaps in the
                          epoch-driven boundary as a point edit. Uses
                          `(int32_t)(now_ms - last_retune_ms)` for
                          wrap-safe elapsed math (mirrors
                          `consider_remote`'s `int32_t` drift idiom);
                          negative reinterpret → `DO_WRAP` so γ-2 can
                          re-anchor `last_retune_ms = now_ms` and the
                          next tick evaluates cleanly. Priority order:
                          NOT_INIT > BUSY > timing (NOT_INIT first so
                          an un-init'd scheduler surfaces as the most
                          actionable diagnostic even on the legacy
                          single-channel path). `DIM = 5` constant
                          pinned to `max-enum + 1`. Enum numeric
                          values pinned (FCC-B1-SUMMARY's additive URC
                          will index counters by these values —
                          reordering would silently mis-route
                          histograms). Evidence:
                          `mingw32-make check` → `[PASS]
                          rx_retune_policy: 14 cases` (NOT_INIT-vs-busy
                          and NOT_INIT-vs-time priority, BUSY-defers-
                          past-period, same-tick / period-1 / =period
                          / period+1 / max-int32-positive forward
                          deltas, small + large backwards-delta wrap,
                          real-uint32-tick-wrap both
                          insufficient-elapsed and sufficient-elapsed
                          branches, DIM-matches-max-enum, enum-
                          numeric-stable) + all 8 previous host tests
                          still green + `[OK] memory map invariants
                          hold`.
                    - [x] **FCC-A6b-2-ii-γ-2** Retune mechanism +
                          `sx1276_rx_tick(now_ms)` API in
                          `sx1276_rx.c`: consults the γ-1 policy and
                          on `DO` performs standby →
                          `sx1276_fhss_next_channel` →
                          `sx1276_set_frequency_hz` →
                          `pll_settle_busy_wait(SX1276_TX_PLL_SETTLE_US)`
                          → re-arm RX. Per-outcome counter TU
                          (HW-free) mirroring the A6b-2-ii-β snap
                          counters. Main-loop wire-up via
                          `sx1276_rx_tick(millis())`. Gated by
                          `LIFETRAC_FHSS_TX_ROUTED`.
                          - Done 2026-05-20. API surface added to
                            [include/sx1276_rx.h](DESIGN-CONTROLLER/firmware/murata_l072/include/sx1276_rx.h):
                            `sx1276_rx_tick(uint32_t now_ms)`,
                            `sx1276_rx_retune_counts(out[DIM])`,
                            `sx1276_rx_retune_counts_reset()`,
                            `sx1276_rx_retune_counter_record(dec)`.
                            HW-free counter TU at
                            [radio/sx1276_rx_retune_counters.c](DESIGN-CONTROLLER/firmware/murata_l072/radio/sx1276_rx_retune_counters.c)
                            (NULL-safe getter, out-of-range no-op,
                            saturating @ UINT32_MAX, DIM = 5).
                            HW mechanism appended to
                            [radio/sx1276_rx.c](DESIGN-CONTROLLER/firmware/murata_l072/radio/sx1276_rx.c):
                            first-tick anchors `s_rx_last_retune_ms`
                            without consulting policy; subsequent
                            ticks call `sx1276_rx_retune_eval(...)`
                            with `sx1276_tx_busy()` as `modem_busy`
                            and `sx1276_fhss_is_initialized() != 0U`
                            as `fhss_ready`; every decision is
                            recorded into the counter TU; `DO_WRAP`
                            re-anchors with no HW touch; `DO` does
                            `sx1276_fhss_next_channel` →
                            `sx1276_modes_to_standby` →
                            `sx1276_set_frequency_hz` → PLL settle
                            busy-wait (`SX1276_RX_PLL_SETTLE_US =
                            200 µs`, mirrors the static value in
                            `sx1276_tx.c` with a tracking comment) →
                            `sx1276_rx_arm`; all `SKIP_*` branches
                            are HW no-ops. Unrouted build defines
                            `sx1276_rx_tick` as `(void)now_ms;` so
                            main.c needs no ifdef. Main-loop wire-up
                            in [main.c](DESIGN-CONTROLLER/firmware/murata_l072/main.c)
                            calls `sx1276_rx_tick(now_ms)` inside the
                            existing `{ const uint32_t radio_events
                            = ... }` block (reuses the `now_ms` tick
                            already taken at the top of the loop).
                            Host_stats UNCHANGED (FROZEN per plan);
                            retune counters reach the host via the
                            additive FCC-B1-SUMMARY URC, not via
                            host_stats. γ-2 known limitation: the
                            γ-1 placeholder period (380 ms = dwell
                            cap) means a worst-case in-flight long
                            frame could be interrupted at the
                            boundary; γ-3 closes this by tying the
                            period to the Q2 epoch model so TX and
                            RX retune at the same instant.
                            `modem_busy` here only tracks
                            `sx1276_tx_busy()` — RX-mid-frame is not
                            tracked at this layer (γ-3 / Q2-gated).
                            Evidence: `mingw32-make check` →
                            `[PASS] rx_retune_counters: 10 cases`
                            (initial-state-all-zero, each-slot-
                            isolation, out-of-range-noop, snapshot-
                            readonly, reset-zeroes-then-usable,
                            null-getter-noop, saturating-increment-
                            4096, interleaved-accumulate, DIM-
                            matches-enum, round-trip-after-reset-
                            fresh) + all 9 previous host tests still
                            green + `[OK] memory map invariants
                            hold`.
                    - [ ] **FCC-A6b-2-ii-γ-3** (deferred until Q2
                          closes) Replace the γ-1 placeholder period
                          with the real epoch-driven boundary from the
                          chosen epoch model.
    - [x] **FCC-A6c** Explicit **Scanning** cold-start state: wideband
          scan-with-preamble-timeout across the 50-channel active set,
          re-sync slot per epoch fallback if decode fails for N
          consecutive epochs. No fixed-channel rendezvous (FCC notes
          §15.1.1 retraction). Acceptance target per plan §7 Q6:
          measured worst-case cold-start hop-sync reacquire ≤ 5 s;
          >30 s ⇒ A6 redesign (adaptive scan dwell or super-frame
          beacon slot within the hopset).
          *Closed 2026-05-20 via three sub-tracks all [x]:
          FCC-A6c-1 (pure-function Scanning SM in
          [`radio/sx1276_rx_scan_policy.c`](DESIGN-CONTROLLER/firmware/murata_l072/radio/sx1276_rx_scan_policy.c)
          — BOOT/SCANNING/LOCKED/FAILED, TICK/FRAME_VALID/
          FRAME_INVALID events, six actions, defensive
          FRAME_VALID+header_ok=false demotion, modular-tick wrap
          handling, 20 host cases),
          FCC-A6c-2 (HW dispatch: -2-a parallel per-state +
          per-action saturating counter TU [14 cases]; -2-b
          scan-tick API + frame-event feed wired into three
          `sx1276_rx_service()` call sites; -2-c gates γ-1 retune
          on LOCKED, dispatches BEGIN_SCAN / ADVANCE_CHANNEL via
          standby → next_channel → set_freq → PLL-settle → arm,
          LOCK = HW-no-op since frame was just received on the
          snapped channel, FAIL → standby, HOLD/REANCHOR HW-no-op),
          FCC-A6c-3 (P1 reporting per
          [AI NOTES/2026-05-19_RX_Scan_FAILED_State_Analysis_Copilot_v1_0.md](AI%20NOTES/2026-05-19_RX_Scan_FAILED_State_Analysis_Copilot_v1_0.md)
          §13 v5.0: -3-a `HOST_FAULT_CODE_RX_SCAN_FAILED=0x0D` +
          §13.1 #2 `sub`-byte encoding; -3-b four file-statics
          tracking retries / IRQ-seen / CRC-seen / ever-locked;
          -3-c B-prime retry supervisor with `MAX_RETRIES=3U` +
          12-case host TU pinning bit layout, retry boundary,
          attempt-nibble saturation, defensive NULL contract).
          P2 (Opta-routed indicator) and P3 (RTC-BKP LKG /
          backoff) explicitly deferred per the §13 v5.0
          scope-lock. `mingw32-make check` green throughout
          (12 host suites; memory map invariants hold). Acceptance
          target (≤5 s reacquire) measurement deferred to
          FCC-EVID-D8 bench run.*
        - [x] **FCC-A6c-1** Scanning state-machine pure-function
              policy in
              [`radio/sx1276_rx_scan_policy.c`](DESIGN-CONTROLLER/firmware/murata_l072/radio/sx1276_rx_scan_policy.c)
              + header
              [`include/sx1276_rx_scan_policy.h`](DESIGN-CONTROLLER/firmware/murata_l072/include/sx1276_rx_scan_policy.h).
              State enum (BOOT, SCANNING, LOCKED, FAILED; DIM=4),
              event enum (TICK, FRAME_VALID, FRAME_INVALID; DIM=3),
              action enum (HOLD, BEGIN_SCAN, ADVANCE_CHANNEL, LOCK,
              FAIL, REANCHOR; DIM=6). All numeric values pinned —
              FCC-B1-SUMMARY URC will index per-state / per-action
              histograms by these values. Regulatory constants:
              `SX1276_RX_SCAN_DWELL_MS=100`, `SX1276_RX_SCAN_GOAL_MS=5000`
              (§7 Q6 acceptance target — A6c-3 reports overruns to
              D-Gate, NOT enforced),
              `SX1276_RX_SCAN_REDESIGN_MS=30000` (§7 Q6 redesign
              threshold — enforced as SCANNING→FAILED transition).
              Authenticated-header trust boundary: FRAME_VALID
              requires caller to pre-verify A6a MIC + profile_id +
              schema_ver; policy defensively demotes
              FRAME_VALID+header_ok=false to FRAME_INVALID so it
              never locks onto an unauthenticated frame. Order of
              checks in SCANNING+TICK: cold-anchor wrap → regulatory
              FAIL (cold_elapsed ≥ REDESIGN_MS) → channel-anchor
              wrap → ADVANCE_CHANNEL (channel_elapsed ≥ DWELL_MS) →
              HOLD. Modular arithmetic absorbs the normal 49.7d tick
              wrap; REANCHOR is only emitted when apparent elapsed
              ≥ 2^31 ms (clock glitch / backwards jump). BOOT
              collapses any event to BEGIN_SCAN. LOCKED + FAILED are
              absorbing (LOSS-OF-SYNC re-scan path is deferred until
              the LOCKED-state stale-decode policy lands post-γ-3).
              Wired into [Makefile](DESIGN-CONTROLLER/firmware/murata_l072/Makefile)
              (SRCS, `RX_SCAN_POLICY_BIN`, `.PHONY`, aggregate
              `check`, `check-rx-scan-policy` target with
              `[RXSCN]` label). Evidence: `mingw32-make check` →
              `[PASS] rx_scan_policy: 20 cases` (NULL-safe default,
              BOOT-collapses-all-events, dwell-boundary precedence,
              redesign-boundary FAIL-wins-over-ADVANCE, FRAME_VALID-
              with-bad-header demotion, LOCKED+FAILED absorbing,
              per-anchor REANCHOR detection, DIM-matches-max-enum
              for all three enums, enum-numeric-stability) + all 9
              prior host tests still green + `[OK] memory map
              invariants hold`.
        - [x] **FCC-A6c-2** HW mechanism: wire A6c-1 policy into the
              RX loop. Caller maintains `state`, `channel_entry_ms`,
              `cold_start_entry_ms`; converts modem IRQ + A6a
              header verification result into the input event;
              executes the returned action (BEGIN_SCAN starts
              SCANNING and arms preamble timeout on first scan
              channel; ADVANCE_CHANNEL jumps to next channel in the
              active set and rearms; LOCK extracts epoch/hop_idx
              from header and seeds the FHSS scheduler then
              transitions to γ-1 retune loop; FAIL emits alert URC
              and halts modem; REANCHOR re-anchors both timers).
              HW-free per-state + per-action counter TU mirroring
              γ-2 (host-testable). No host_stats bump (FROZEN).
            - [x] **FCC-A6c-2-a** Counters TU
                  ([`radio/sx1276_rx_scan_counters.c`](DESIGN-CONTROLLER/firmware/murata_l072/radio/sx1276_rx_scan_counters.c)
                  + prototypes in
                  [`include/sx1276_rx_scan_policy.h`](DESIGN-CONTROLLER/firmware/murata_l072/include/sx1276_rx_scan_policy.h)).
                  Two parallel saturating-uint32 histograms — one
                  indexed by `sx1276_rx_scan_state_t` (DIM=4), one
                  by `sx1276_rx_scan_action_t` (DIM=6). Mirrors
                  γ-2 (`sx1276_rx_retune_counters.c`) pattern but
                  spans both axes. Per-axis OOR guards are
                  independent (one bad cast cannot blank the
                  other). Single `record(state, action)` API the
                  RX loop (A6c-2-b) calls once per
                  `sx1276_rx_scan_eval()`. Getters
                  (`sx1276_rx_scan_state_counts`,
                  `sx1276_rx_scan_action_counts`) unconditionally
                  available so FCC-B1-SUMMARY reads without an
                  ifdef wrapper. Single `_counts_reset()` zeros
                  both arrays. No host_stats field, no host↔X8
                  SerialRPC wire bump. Wired into
                  [Makefile](DESIGN-CONTROLLER/firmware/murata_l072/Makefile)
                  (SRCS, `RX_SCAN_COUNTERS_BIN`, `.PHONY`,
                  aggregate `check`, `check-rx-scan-counters`
                  target with `[RXSCC]` label). Evidence:
                  `mingw32-make check` →
                  `[PASS] rx_scan_counters: 14 cases` (zeroed
                  initial state, per-axis slot isolation
                  in-lockstep, OOR-state-keeps-action, OOR-action-
                  keeps-state, both-OOR no-op, idempotent
                  snapshots, reset zeros BOTH, NULL-safe getters,
                  no narrow-type wrap @ 4096 records,
                  interleaved accumulation, STATE_DIM/ACTION_DIM
                  match max-enum + 1, round-trip after reset) +
                  all 10 prior host tests still green +
                  `[OK] memory map invariants hold`.
            - [x] **FCC-A6c-2-b** RX-loop wire-up in
                  `radio/sx1276_rx.c`: maintain SM state +
                  anchors, map modem IRQ + A6a header verification
                  onto event, dispatch action (BEGIN_SCAN /
                  ADVANCE_CHANNEL / LOCK→γ-1 / FAIL / REANCHOR),
                  call `sx1276_rx_scan_counter_record()` once per
                  eval.
                - [x] **FCC-A6c-2-b-i** Scanning tick API +
                      observe-only bookkeeping. New
                      `sx1276_rx_scan_tick(now_ms)` in
                      [`radio/sx1276_rx.c`](DESIGN-CONTROLLER/firmware/murata_l072/radio/sx1276_rx.c)
                      (prototype in
                      [`include/sx1276_rx.h`](DESIGN-CONTROLLER/firmware/murata_l072/include/sx1276_rx.h))
                      maintains file-static `s_scan_state` +
                      `s_scan_channel_entry_ms` +
                      `s_scan_cold_start_entry_ms`; per tick
                      builds an A6c-1 input with `event=TICK`,
                      calls `sx1276_rx_scan_eval()`, records the
                      observed (state, action) pair via the
                      A6c-2-a counters TU, updates anchors per
                      action (BEGIN_SCAN/REANCHOR ⇒ both,
                      ADVANCE_CHANNEL ⇒ channel only, others ⇒
                      unchanged), and stores `next_state` back.
                      Routed-build only — no-op when
                      `LIFETRAC_FHSS_TX_ROUTED` undefined. Called
                      from
                      [`main.c`](DESIGN-CONTROLLER/firmware/murata_l072/main.c)
                      BEFORE `sx1276_rx_tick()` so the γ-1
                      retune gating (A6c-2-c) will see the
                      freshly-updated SM state. **Observe-only**:
                      no modem standby / set_freq / arm / disarm
                      is driven by any scan-SM action this
                      increment — the existing γ-1 retune loop
                      and main.c `sx1276_rx_arm()` continue
                      unchanged. Counter histograms pre-A6c-2-c
                      will show BOOT→BEGIN_SCAN exactly once at
                      first tick, then SCANNING+TICK
                      accumulating with ADVANCE_CHANNEL ticking
                      every 100 ms and FAIL firing at
                      cold_elapsed ≥ 30 s — no FRAME_VALID /
                      FRAME_INVALID histograms (those land in
                      A6c-2-b-ii). Evidence: `mingw32-make
                      check` → all 11 host tests green +
                      `[OK] memory map invariants hold` (the
                      cross-target firmware compile validates
                      the new TU once an arm-none-eabi
                      toolchain is available; the host check
                      preprocesses `sx1276_rx_scan_policy.h`
                      cleanly via the existing scan_policy /
                      scan_counters TU host tests).
                - [x] **FCC-A6c-2-b-ii** Frame-event wire-up in
                      `sx1276_rx_service()`: after A6a header
                      parse, drive `sx1276_rx_scan_eval()` with
                      `event=FRAME_VALID, frame_header_valid=
                      true` on parse OK and `event=FRAME_INVALID`
                      on parse fail / CRC error / wrong schema,
                      then `sx1276_rx_scan_counter_record()`.
                    - [x] **FCC-A6c-2-b-ii-α** Shared SM driver +
                          frame-event feed plumbing. Refactored
                          [`radio/sx1276_rx.c`](DESIGN-CONTROLLER/firmware/murata_l072/radio/sx1276_rx.c)
                          to extract a static `scan_drive(event,
                          header_valid, now_ms)` helper shared by
                          `sx1276_rx_scan_tick()` and a new static
                          `scan_feed_frame(header_valid)` that
                          samples `platform_now_ms()` and drives
                          the SM with `FRAME_VALID` /
                          `FRAME_INVALID`. Wired three call sites
                          in `sx1276_rx_service()`: (1) payload
                          CRC error → `scan_feed_frame(false)`
                          before IRQ ack; (2) post-RX_DONE A6a
                          `lora_pkt_hdr_unpack()` failure (bad
                          schema / short frame) → `scan_feed_frame
                          (false)`; (3) post-RX_DONE header OK +
                          `sx1276_fhss_consider_remote()` →
                          `scan_feed_frame(true)`. All three are
                          inside `#ifdef LIFETRAC_FHSS_TX_ROUTED`
                          so the unrouted build is unchanged.
                          **Still observe-only**: SM transitions
                          to LOCKED on FRAME_VALID(header_ok=true)
                          and the (state, action) counter records
                          it, but no HW dispatch — γ-1 retune
                          continues unconditionally and main.c
                          arm/disarm is unchanged. A6c-2-c gates
                          γ-1 on LOCKED and adds modem standby /
                          set_freq / arm dispatch off scan
                          actions. Evidence: `mingw32-make check`
                          → all 11 host tests green +
                          `[OK] memory map invariants hold`; the
                          three call sites compile inside the
                          existing routed ifdef without
                          duplicating frame-parse logic.
                - [x] **FCC-A6c-2-c** HW dispatch: gate the γ-1
                      retune tick on `s_scan_state == LOCKED`;
                      wire BEGIN_SCAN (anchor + initial channel
                      arm), ADVANCE_CHANNEL (standby → next
                      channel from FHSS → set_freq → settle →
                      RX-arm), LOCK (seed FHSS from header
                      epoch/hop_idx then transition to γ-1
                      loop), FAIL (alert URC + standby).
                    - [x] **FCC-A6c-2-c-i** γ-1 LOCKED gate +
                          BEGIN_SCAN / ADVANCE_CHANNEL HW
                          dispatch. New static
                          `scan_dispatch_action(action)` in
                          [`radio/sx1276_rx.c`](DESIGN-CONTROLLER/firmware/murata_l072/radio/sx1276_rx.c)
                          executes the standby → `sx1276_fhss_next
                          _channel()` → `sx1276_set_frequency_hz()`
                          → PLL-settle (`SX1276_RX_PLL_SETTLE_US`
                          = 200 µs, mirrors γ-2) →
                          `sx1276_rx_arm()` sequence for both
                          BEGIN_SCAN and ADVANCE_CHANNEL; called
                          from `scan_drive()` AFTER state +
                          anchors are committed so a re-entrant
                          IRQ during the standby window observes
                          the new state. HOLD / LOCK / FAIL /
                          REANCHOR remain HW-no-op pending
                          A6c-2-c-ii. `sx1276_rx_tick()` (γ-1)
                          now early-returns unless `s_scan_state
                          == LOCKED` and resets
                          `s_rx_last_retune_ms_valid = 0` while
                          gated out, so the first tick post-LOCK
                          re-anchors cleanly instead of firing a
                          spurious DO_WRAP off stale pre-LOCK
                          timing. File-statics `s_scan_state` /
                          `s_scan_channel_entry_ms` /
                          `s_scan_cold_start_entry_ms` were moved
                          to the top of the routed block (default
                          zero-init = `SX1276_RX_SCAN_STATE_BOOT`)
                          so γ-1 can read `s_scan_state`. Scan
                          dispatcher and γ-1 are now mutually
                          exclusive owners of the synth: scan SM
                          owns it in BOOT / SCANNING / FAILED;
                          γ-1 owns it in LOCKED. Evidence:
                          `mingw32-make check` → all 11 host
                          tests green + `[OK] memory map
                          invariants hold`.
                    - [x] **FCC-A6c-2-c-ii** LOCK + FAIL HW
                          dispatch. LOCK case in
                          `scan_dispatch_action()` is
                          intentionally HW-no-op (frame that
                          triggered LOCK was just received in
                          RX-cont so the modem is already armed
                          on the snapped channel;
                          `sx1276_fhss_consider_remote()` already
                          aligned the FHSS pointer; the next
                          `sx1276_rx_tick()` opens the LOCKED
                          gate and γ-1 takes the synth — driving
                          an extra standby + arm here would only
                          add a needless RX gap right after first
                          contact). FAIL case calls
                          `sx1276_modes_to_standby()` so the
                          modem stops listening on a dead
                          hopset; FAILED is the A6c-1 absorbing
                          state so this single standby is
                          sufficient until external recovery.
                          HOLD / REANCHOR remain HW-no-op (no
                          transition / clock-glitch anchor reset
                          only). Alert URC deliberately deferred
                          to FCC-A6c-3 / FCC-B1-SUMMARY to keep
                          this increment within the frozen
                          host↔X8 wire layout (no new SerialRPC
                          URC codes in the A6c-2 sub-track).
                          Evidence: `mingw32-make check` → all
                          11 host tests green + `[OK] memory map
                          invariants hold`.
        - [x] **FCC-A6c-3** Reporting: 5 s acceptance-target overrun
              counter + FAIL-cause URC (additive to B1-SUMMARY).
              D-Gate analyzes the overrun rate.
              Scope locked by
              [AI NOTES/2026-05-19_RX_Scan_FAILED_State_Analysis_Copilot_v1_0.md](AI%20NOTES/2026-05-19_RX_Scan_FAILED_State_Analysis_Copilot_v1_0.md)
              §13 (v5.0): Phase P1 only (bounded retries + four-class
              `sub`-byte disambiguation); P2 (Opta-routed indicator)
              and P3 (RTC-BKP LKG / backoff) explicitly deferred.
            - [x] **FCC-A6c-3-a** Add
                  `HOST_FAULT_CODE_RX_SCAN_FAILED = 0x0DU` to
                  [`include/host_types.h`](DESIGN-CONTROLLER/firmware/murata_l072/include/host_types.h)
                  with the §13.1 #2 `sub`-byte encoding documented in
                  a comment block above the define. Declaration-only;
                  no emitter yet. Evidence: `mingw32-make check` →
                  all 11 host tests green + `[OK] memory map
                  invariants hold`.
            - [x] **FCC-A6c-3-b** Add the four file-statics
                  (`s_scan_fail_retries`, `s_scan_got_any_irq`,
                  `s_scan_crc_seen`, `s_scan_ever_locked_this_boot`)
                  to `radio/sx1276_rx.c`; hook
                  `s_scan_got_any_irq` / `s_scan_crc_seen` in
                  `sx1276_rx_service()`; clear on
                  `BEGIN_SCAN`/`ADVANCE_CHANNEL`; reset on `LOCK`;
                  set `s_scan_ever_locked_this_boot` on `LOCK`. **Do
                  not** emit the fault URC yet. Evidence:
                  `mingw32-make check` → all 11 host tests green +
                  `[OK] memory map invariants hold`.
            - [x] **FCC-A6c-3-c** Wire B-prime retry supervisor +
                  `host_cmd_emit_fault(HOST_FAULT_CODE_RX_SCAN_FAILED,
                  sub)` into `scan_dispatch_action(FAIL)` per
                  §13.1 #6; land HW-free retry/`sub`-byte wrapper
                  test (≥8 cases) under
                  [`bench/host_proto/`](DESIGN-CONTROLLER/firmware/murata_l072/bench/host_proto/).
                  Evidence: pure helper landed at
                  [`radio/sx1276_rx_scan_fail.c`](DESIGN-CONTROLLER/firmware/murata_l072/radio/sx1276_rx_scan_fail.c)
                  + [`include/sx1276_rx_scan_fail.h`](DESIGN-CONTROLLER/firmware/murata_l072/include/sx1276_rx_scan_fail.h)
                  (defines `SX1276_RX_SCAN_MAX_RETRIES = 3U` per
                  v5.0 §13.1). Dispatcher emits the URC and either
                  absorbs in `FAILED` (final) or re-enters `SCANNING`
                  with anchor reset + recursive `BEGIN_SCAN` HW
                  sequence (non-final). Host test
                  [`bench/host_proto/rx_scan_fail.c`](DESIGN-CONTROLLER/firmware/murata_l072/bench/host_proto/rx_scan_fail.c)
                  pins the §13.1 #2 bit layout, retry boundary,
                  attempt-nibble saturation, warm/hw_suspect/
                  crc_seen derivation, NULL-input defensive
                  contract, and `MAX_RETRIES==3U` constant —
                  12 cases. `mingw32-make check` → all 12 host
                  tests green + `[OK] memory map invariants hold`.
- [x] **FCC-B1-SUMMARY** Per-minute `RFCO_SUMMARY` URC: 50-bucket
      histogram, per-channel `legal_dwell_max_us`, `blocked_attempts`
      histogram, `active_count`, `blacklist_size`, last clamp reason,
      RFCO schema version. **Wire layout + cadence design**:
      [AI NOTES/2026-05-19_FCC_B1_SUMMARY_Wire_Layout_Design_Copilot_v1_0.md](AI%20NOTES/2026-05-19_FCC_B1_SUMMARY_Wire_Layout_Design_Copilot_v1_0.md)
      — 191 B payload, single frame, snapshot-and-reset deltas, main-loop
      polling cadence at 60 000 ms, `HOST_TYPE_RFCO_SUMMARY_URC = 0xC4U`.
      *Closed 2026-05-20 via FCC-B1-SUMMARY-a (declaration-only header
      with `HOST_RFCO_SUMMARY_SCHEMA_VER=1`, payload-length /
      channel-count / reason-slots static_asserts, and the
      `HOST_TYPE_RFCO_SUMMARY_URC=0xC4U` host-type allocation),
      FCC-B1-SUMMARY-b (pure `host_rfco_summary_pack()` plus three
      sidecar saturating counter modules — `sx1276_fhss` per-channel
      hop counts, `sx1276_legal_dwell` per-channel peak-used-µs,
      `host_rfco` `blocked_attempts_by_reason` slot map — with full
      byte-by-byte wire-vector coverage in
      [bench/host_proto/rfco_summary.c](DESIGN-CONTROLLER/firmware/murata_l072/bench/host_proto/rfco_summary.c)
      and `rfco_summary_counters.c`), and FCC-B1-SUMMARY-c (emit
      wrapper with `HOST_RFCO_SUMMARY_PERIOD_MS=60000` cadence,
      monotonic `platform_now_ms()` wraparound safety, `FIRST` flag
      arming, `seq` counter, and `window_elapsed_ms` jitter
      reporting — verified by `rfco_summary_integration: 8 cases`).
      `mingw32-make check` green throughout (17 host suites). All
      seven required telemetry fields covered: per-channel hop
      histogram (50 u8), per-channel legal-dwell peak (50 u16),
      blocked-attempts histogram (8 u16 slots), active_count,
      blacklist_size, last clamp reason, schema version — matching
      the parent's bullet list one-for-one. No outstanding sub-work;
      gate is field-ready.*
  - [x] **FCC-B1-SUMMARY-a** Declaration-only — *done 2026-05-19.
        Added [include/host_rfco_summary.h](DESIGN-CONTROLLER/firmware/murata_l072/include/host_rfco_summary.h)
        with `HOST_RFCO_SUMMARY_SCHEMA_VER=1`,
        `HOST_RFCO_SUMMARY_PAYLOAD_LEN=191`,
        `HOST_RFCO_SUMMARY_PERIOD_MS=60000`,
        `HOST_RFCO_SUMMARY_CHANNEL_COUNT=50`,
        `HOST_RFCO_SUMMARY_REASON_SLOTS=8`, full byte-offset macro set,
        `host_rfco_summary_t` snapshot struct mirroring §3 of the design
        doc, and 4 `_Static_assert`s (payload_len==191, channel count
        matches `SX1276_FHSS_CHANNEL_COUNT`, payload ≤ `HOST_PAYLOAD_MAX_LEN`,
        reason slots ≥ 7). Added
        `HOST_TYPE_RFCO_SUMMARY_URC = 0xC4U` to
        [include/host_types.h](DESIGN-CONTROLLER/firmware/murata_l072/include/host_types.h)
        with cross-ref comment block. No emitter, no pack helper, no
        main-loop integration — those land in B1-SUMMARY-b and -c.
        Verified: standalone `gcc -fsyntax-only` on the header parses
        clean (all 4 static_asserts hold); `mingw32-make check` green
        (12 host suites pass, memory map invariants hold).*
  - [x] **FCC-B1-SUMMARY-b** Pure pack helper
        `host_rfco_summary_pack()` + 3 sidecar counter TUs (per-channel
        hop-count, per-channel dwell-max-ms, blocked-attempts-by-reason)
        + ≥10 byte-by-byte wire-vector cases in
        `bench/host_proto/rfco_summary.c`. — *done 2026-05-19 across
        three sub-bullets b-1, b-2, b-3 below.*
    - [x] **b-1** Three sidecar counter TUs in isolation — *done
          2026-05-19. Added saturating-record + snapshot-and-clear APIs
          to three modules:
          (1) [radio/sx1276_fhss.c](DESIGN-CONTROLLER/firmware/murata_l072/radio/sx1276_fhss.c)
          + [include/sx1276_fhss.h](DESIGN-CONTROLLER/firmware/murata_l072/include/sx1276_fhss.h)
          — `sx1276_fhss_record_hop(idx)` + `sx1276_fhss_hop_count_snapshot_and_clear(out[50])`
          (u16 in-memory, saturates to 0xFFU on wire);
          (2) [radio/sx1276_legal_dwell.c](DESIGN-CONTROLLER/firmware/murata_l072/radio/sx1276_legal_dwell.c)
          + [include/sx1276_legal_dwell.h](DESIGN-CONTROLLER/firmware/murata_l072/include/sx1276_legal_dwell.h)
          — `peak_used_us[64]` tracked on every successful `reserve()` as
          `used_before + pessimistic_us`, plus
          `sx1276_legal_dwell_peak_us_snapshot_and_clear(out[64])`;
          failed reservations (BAD_CH/BAD_RESERVE/OVER_BUDGET) do NOT
          update peak;
          (3) [host/host_rfco.c](DESIGN-CONTROLLER/firmware/murata_l072/host/host_rfco.c)
          + [include/host_rfco.h](DESIGN-CONTROLLER/firmware/murata_l072/include/host_rfco.h)
          — `host_rfco_blocked_attempts_record(reason)` /
          `_snapshot_and_clear(out[8])` / `_reset()` with documented
          slot map (OK never recorded; reasons 1..6 → slots 1..6;
          INTERNAL 0xFF → slot 7; unallocated values dropped; u16
          saturating). All three counter pairs are NULL-safe (out=NULL
          preserves) and OOR-safe (bad idx is a no-op). New bench TU
          [bench/host_proto/rfco_summary_counters.c](DESIGN-CONTROLLER/firmware/murata_l072/bench/host_proto/rfco_summary_counters.c)
          with 17 cases (record→snapshot→re-snapshot zero; wire-byte
          saturation; in-memory u16 saturation past UINT16_MAX;
          per-channel/per-slot independence; monotonic high-water
          mark; failed-reserve no-update; NULL preserves; OK never
          recorded; INTERNAL→slot 7; unallocated reason dropped).
          New Makefile target `check-rfco-summary-counters` added to
          `check:` chain. NO call-site wiring (TX-success → record_hop,
          legal-dwell → already integrated in reserve(), TX-abort →
          record_blocked) — that lands in B1-SUMMARY-b-3. Verified:
          `mingw32-make check` green (14 host suites pass including
          `rfco_summary_counters: 17 cases`, memory map invariants
          hold).*
    - [x] **b-2** Pure pack helper + byte-by-byte wire vectors — *done
          2026-05-19. Added
          [host/host_rfco_summary.c](DESIGN-CONTROLLER/firmware/murata_l072/host/host_rfco_summary.c)
          with `host_rfco_summary_pack(const host_rfco_summary_t *in,
          uint8_t out[191])` (no HAL deps; pure serialize) and
          declared in
          [include/host_rfco_summary.h](DESIGN-CONTROLLER/firmware/murata_l072/include/host_rfco_summary.h).
          Layout invariants enforced by the helper itself:
          (a) byte 0 hard-pinned to `HOST_RFCO_SUMMARY_SCHEMA_VER`
          (struct `schema_ver` field ignored, documentation-only);
          (b) bytes 6..7 (`_reserved_align`) hard-zeroed regardless of
          struct field (suppresses uninit-struct leaks; any future use
          MUST bump SCHEMA_VER);
          (c) CRC-16/CCITT-FALSE (poly 0x1021, init 0xFFFF, no reflect,
          xorout 0x0000) over bytes [0..188] written LE at [189..190].
          Added `host_rfco_summary.c` to firmware `SRCS` so the target
          toolchain also compile-checks it. New bench TU
          [bench/host_proto/rfco_summary.c](DESIGN-CONTROLLER/firmware/murata_l072/bench/host_proto/rfco_summary.c)
          with 17 cases: CRC-16/CCITT-FALSE KAT (crc("123456789") ==
          0x29B1); NULL `in` rejected without touching out; NULL `out`
          rejected; payload_len pin; schema byte hard-pin under struct
          lie (0xAA → still 0x01 on wire); pertx_schema_ver_at_emit
          stamp; `_reserved_align` hard-zero under struct poison
          (0xDEAD → 00 00); all-zero snapshot golden (only byte 0 +
          CRC non-zero); u32 LE encoding for uptime/seq/window_elapsed
          (spot-checked byte order 0x12345678 → 78 56 34 12);
          per-channel hop-count[50] byte-for-byte round-trip with 0xFF
          saturation; per-channel dwell_max_ms[50] u16 LE round-trip
          with 0xFFFF saturation; blocked_attempts_by_reason[8] u16 LE
          round-trip (spot-checked 0xABCD → CD AB); tail bytes
          (pertx_count_in_window / summary_emit_count / flags); flags
          FIRST_SINCE_BOOT bit; CRC byte order (LE); CRC sensitivity
          (flipping any of 15 representative bytes in [0..188] changes
          the CRC); repack overwrites pre-poisoned CRC bytes. New
          Makefile target `check-rfco-summary` added to `check:` chain.
          NO call-site wiring (snapshot consumer + emit() land in b-3
          and -c). Verified: `mingw32-make check` green (15 host
          suites pass including `rfco_summary: 17 cases`, memory map
          invariants hold).*
    - [x] **b-3** Call-site wiring at the per-TX emit boundary — *done
          2026-05-19. Wired the two TX-driven sidecar counters into
          [host/host_rfco.c](DESIGN-CONTROLLER/firmware/murata_l072/host/host_rfco.c)
          `host_rfco_pertx_emit()` so every accepted per-TX URC also
          updates the per-minute SUMMARY URC inputs:
          (1) `host_rfco_blocked_attempts_record(snapshot->tx_status)`
          called on every accepted emit (record() handles the OK skip
          internally, so slot 0 stays reserved);
          (2) `sx1276_fhss_record_hop(snapshot->hop_idx)` called iff
          `snapshot->tx_status == HOST_RFCO_TX_STATUS_OK` (a blocked
          TX never went on air, so it must NOT inflate the per-channel
          hop histogram). NULL snapshot short-circuits before either
          counter is touched. Legal-dwell counter was already wired in
          b-1 (inside `sx1276_legal_dwell_reserve()`), so all three
          SUMMARY sidecars now self-populate from the live TX path
          without sx1276_tx.c needing any changes. Extended
          [bench/host_proto/rfco_pertx.c](DESIGN-CONTROLLER/firmware/murata_l072/bench/host_proto/rfco_pertx.c)
          with 5 new cases (now 11 total): hop_count bumps on OK and
          ONLY on OK; blocked_attempts[slot=2] on ABORT_LBT;
          blocked_attempts[slot=7] on INTERNAL (0xFF remap); 5x
          repeated emit accumulates hop_count[N]==5; emit(NULL) does
          NOT touch either counter. Updated `check-rfco-pertx`
          Makefile target to link `radio/sx1276_fhss.c` +
          `radio/sx1276_fhss_chantab.c` (host_rfco.c now references
          `sx1276_fhss_record_hop`). Verified: `mingw32-make check`
          green (15 host suites pass including
          `rfco_pertx: 11 cases`, memory map invariants hold).
          Closes FCC-B1-SUMMARY-b parent; B1-SUMMARY-c (emit wrapper +
          60 000 ms main-loop cadence) is now unblocked.*
  - [x] **FCC-B1-SUMMARY-c** Emit wrapper
        `host_rfco_summary_emit()` + main-loop 60 000 ms cadence
        integration + emit-timing bench test. *done 2026-05-19 via
        c-1 (emit wrapper + per-window sidecars) + c-2 (main-loop
        wiring + integration bench). Closes FCC-B1-SUMMARY entirely
        — unblocks FCC-B2-b (artifact-header stamping can now source
        `rfco_schema_ver` from the SUMMARY URC wire byte 0).*
    - [x] **c-1** Emit wrapper + cadence helper + per-window sidecars
          — *done 2026-05-19. Added 4-function per-window sidecar API
          in [include/host_rfco.h](DESIGN-CONTROLLER/firmware/murata_l072/include/host_rfco.h)
          (`host_rfco_pertx_window_record`,
          `_count_in_window_snapshot_and_clear`,
          `host_rfco_last_clamp_reason_snapshot_and_clear`,
          `_pertx_window_reset`) with internal u16 saturating counter +
          u8 wire clamp + 0xFF sentinel for "no clamp this window".
          Implemented sidecars in
          [host/host_rfco.c](DESIGN-CONTROLLER/firmware/murata_l072/host/host_rfco.c)
          (literal `0xFFU` used to avoid summary.h ↔ host_rfco.h
          include cycle) and wired the recorder into
          `host_rfco_pertx_emit()` AFTER the b-3 blocked_attempts +
          conditional hop_count block so every accepted per-TX URC also
          bumps the per-window counters. Added emit wrapper +
          cadence helper to
          [include/host_rfco_summary.h](DESIGN-CONTROLLER/firmware/murata_l072/include/host_rfco_summary.h):
          `host_rfco_summary_emit(seq, now_ms, window_elapsed_ms,
          profile_id)`, `host_rfco_summary_should_emit(now, last)`
          (u32-wraparound-safe), `host_rfco_summary_reset_wrapper_state()`
          (test-only). Implementation lives in a new TU
          [host/host_rfco_summary_emit.c](DESIGN-CONTROLLER/firmware/murata_l072/host/host_rfco_summary_emit.c)
          (split from `host_rfco_summary.c` so the b-2 pack-only bench
          stays HAL-free): builds `host_rfco_summary_t` from live
          sidecars (`sx1276_fhss_active_count`,
          `hop_count_snapshot_and_clear`,
          `sx1276_legal_dwell_peak_us_snapshot_and_clear` with µs→ms
          ceiling-div u16 saturation, `blocked_attempts_snapshot_and_clear`,
          new `pertx_count_in_window` + `last_clamp_reason` sidecars),
          packs to 191 B, forwards to `host_uart_send_urc(0xC4,
          (uint16_t)(seq&0xFFFF), flags, payload, 191)`. State advance
          (FIRST_SINCE_BOOT latch, `summary_emit_count` saturating u8)
          happens AFTER the send so a pack failure preserves the
          FIRST bit for retry. No main-loop wiring — that lands as
          c-2. Added new Makefile target `check-rfco-summary-emit`
          (links the new TU + `host_rfco.c` + `sx1276_fhss.c` +
          `_fhss_chantab.c` + `_legal_dwell.c`) in
          [DESIGN-CONTROLLER/firmware/murata_l072/Makefile](DESIGN-CONTROLLER/firmware/murata_l072/Makefile)
          and added `host/host_rfco_summary_emit.c` to firmware SRCS.
          New bench
          [bench/host_proto/rfco_summary_emit.c](DESIGN-CONTROLLER/firmware/murata_l072/bench/host_proto/rfco_summary_emit.c)
          covers 9 cases: (1) emit forwards (type=0xC4, seq low 16,
          flags, payload, len=191) to stubbed send_urc; (2) payload
          matches independent re-pack with hand-built snapshot
          mirroring populated sidecars; (3) FIRST_SINCE_BOOT latch
          set then cleared; (4) summary_emit_count 0→1→2; (5) every
          sidecar drained by emit (hop_count, dwell_peak,
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

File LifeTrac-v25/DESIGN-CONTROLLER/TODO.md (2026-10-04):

# LifeTrac v25 Controller — Development TODO

> **📋 Pre-deployment summary:** for a single consolidated view of
> what still has to happen across all subsystems before field
> deployment (controller + structural + hydraulic + integration +
> field tests + regulatory), see the
> **[Pre-field-deployment checklist](../TODO.md#pre-field-deployment-checklist-open-items-as-of-2026-05-04)**
> section in the top-level [LifeTrac-v25/TODO.md](../TODO.md). This
> file remains the authoritative source for the controller-side phase
> plan; the top-level checklist links back to specific items here.

> **Scope (2026-04-26):** LoRa-only per [MASTER_PLAN.md](MASTER_PLAN.md). Cellular (Cat-M1 / SARA-R412M) line items below are **archived** — do not order, do not implement. Operator-browser ↔ base-station LAN/WiFi is retained. Legacy WiFi/BLE/MQTT-over-WiFi work is in [RESEARCH-CONTROLLER/](RESEARCH-CONTROLLER/).
>
> **Image-pipeline scope (2026-04-27):** see the canonical [IMAGE_PIPELINE.md](IMAGE_PIPELINE.md) implementation plan. The image-pipeline tasks in Phases 4–5 below are pulled from that plan; if they ever drift, IMAGE_PIPELINE.md is the source of truth.
>
> **LoRa system scope (2026-04-27):** see the canonical [LORA_IMPLEMENTATION.md](LORA_IMPLEMENTATION.md) implementation plan. The LoRa-stack tasks scattered across Phases 1–5 below are pulled from that plan; if they ever drift, LORA_IMPLEMENTATION.md is the source of truth for *what to build*, [LORA_PROTOCOL.md](LORA_PROTOCOL.md) for the wire bytes, and [MASTER_PLAN.md §8.17](MASTER_PLAN.md) for PHY policy pins.

Comprehensive task list for implementing the three-tier controller architecture (Portenta Max Carrier on tractor + Portenta Max Carrier with X8 base station + MKR WAN 1310 handheld). See [ARCHITECTURE.md](ARCHITECTURE.md) for the design.

Tasks are organized by phase. Hardware purchases come first because lead times dominate the schedule.

## Go/No-Go Blockers (Current)

> **Current gate state (refreshed 2026-05-12 evening):** **CONDITIONAL GO** — every original Stage 1 blocker (W1-7 LPUART1 RX, W1-9d PB6 TCXO + SYSCLK, W1-9e urc_queue, W1-9f benign FAULT_URC filter, W1-9b T2 + W1-9g post-VER STATS dispatch stall) is CLOSED with bench evidence. **W1-10 Phase A (single-board RX liveness) closed 2026-05-12 evening — 7/7 gates PASS first run** (`bench-evidence/W1-10_rx_liveness_2026-05-11_133459/`: `RegOpMode=0x85` stuck pre/post, `RegRssiValue` -120 → -119 dBm with AGC twitch, `radio_state=4` RX_CONT, host invariants stable, 0 real FAULT_URC across 10 s window). Stage 1 standard quant **20/20 PASS** (W1-7), then **3/3 PASS** post-W1-9g regression. Stage 2 **TX probe 7/7 PASS** (W1-9f, `tx_id=0x42 status=OK time_on_air_us=18048 tx_power_dbm=14`). Stage 2 **FSK STDBY probe `probe_rc=0`** (W1-9g, mode bits 2:0 transition 0→1 = SX1276 clock alive). Build artifact 16,440 B. The **single remaining gate before unconditional GO** is **W1-10 Phase B** (two-board end-to-end ≥99% match rate) — **probe code SHIPPED 2026-05-11 evening** ([`run_w1_10b_rx_pair_end_to_end.ps1`](firmware/x8_lora_bootloader_helper/run_w1_10b_rx_pair_end_to_end.ps1) + `--probe rx_listen` / `--probe tx_burst` sub-modes); RX-side smoke-tested PASS in single-board mode; orchestrator gracefully refuses to run with one board absent. **Execution blocked only on Board 1 (`2D0A1209DABC240B`) returning to the bench** — design + execution recipe captured in [`../AI NOTES/2026-05-12_W1-10_RX_Validation_Plan_Copilot_v1_0.md`](../AI%20NOTES/2026-05-12_W1-10_RX_Validation_Plan_Copilot_v1_0.md) §3.5.
>
> **Historical reframing (2026-05-11) — preserved for traceability:** the official Arduino BSP overlay [`ov_carrier_enuc_lora.dts`](https://raw.githubusercontent.com/arduino/meta-arduino/scarthgap/meta-arduino-nxp/recipes-bsp/device-tree/arduino-device-tree/portenta-x8/overlays/ov_carrier_enuc_lo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) shows the i.MX `UART4` ↔ Murata link is **direct TX/RX with no Linux-controlled mux/SEL/OE/EN** — only `H747.PF4` as `NRST`. The pad config is `0x140` (= `PE | PUE`, internal pull-up already enabled — see Step 1 below). This invalidated the Phase A–D GPIO-sweep premise and re-scoped the blockers around (a) i.MX pad pull-up, (b) L072 host UART AF mismatch (LPUART1/AF6 vs USART2/AF4), (c) NRST → first-byte timing alignment. Full synthesis: [`2026-05-11_Blocker_Research_Synthesis_Copilot_v1_0.md`](../AI%20NOTES/2026-05-11_Blocker_Research_Synthesis_Copilot_v1_0.md).

### Action plan (REVISED 2026-05-11 02:30 — major win: HSI16 root cause fixed)

> **2026-05-11 status update:** Step 1' (hello_world decisive test) **PASSED** — `"LIFETRAC L072 tick=0x0000006D"` etc captured cleanly at 19200 8N1, isolating the bug to the production firmware. Step 2' audit then found the root cause: `platform_clock_init_hsi16()` in [`hal/platform.c`](firmware/murata_l072/hal/platform.c) called `RCC_CR &= ~RCC_CR_HSION` after switching SYSCLK to HSE, but [`host_uart_init()`](firmware/murata_l072/host/host_uart.c) explicitly clocks LPUART1 from HSI16 via `CCIPR[11:10]=10`. Disabling HSION cut the LPUART1 baud-rate generator's clock → no TX, no RX, ever. **Fix applied** (don't disable HSI16 in platform.c; defensively re-enable in host_uart.c). After re-flash, the production firmware now emits **BOOT_URC (0xF0), READY_URC (0xF2), STATS/FAULT URCs (0xF1)**, plus the diagnostic ASCII traces `M:RADIO_BYPASS`, `C:SEND_BOOT`, `C:SEND_READY`, `C:INIT_DONE` — all visible in the wrapper's `early_921600_bytes=310` capture. **Primary blocker (LPUART1 silent on /dev/ttymxc3) is CLEARED.** A secondary, smaller bug remains: LPUART1 RX is not receiving the probe's `VER_REQ` (firmware emits `HOST_RX_INACTIVE` fault code 0x0A after 3 s) — see Step 6 below.
>
> **Earlier corrections (preserved):** the original Step 1 (pad pull-up) and Step 2-as-BRR-fix sub-hypothesis were invalidated by primary-source verification. The standard Stage 1 quant `BOOT_OK=1` was a false positive (loopback echo on `/dev/ttymxc0`, 0 bytes on the actual `/dev/ttymxc3`). The Step 0 bench regression was recovered without power-cycle via `gpio10` toggle (i.MX→H7 NRST) + `systemctl restart m4-proxy.service`. See [`../AI NOTES/2026-05-11_Blocker_Research_Synthesis_Copilot_v1_0.md`](../AI%20NOTES/2026-05-11_Blocker_Research_Synthesis_Copilot_v1_0.md).

- [x] **Step 0 — Bench recovery.** Resolved 2026-05-10 without power-cycle: pulse `/sys/class/gpio/gpio10` low/high (i.MX GPIO1_IO10 = H7 NRST per `/usr/arduino/extra/reset.sh`) then `systemctl restart m4-proxy.service`. SWD returned `DPIDR 0x6ba02477`.

- [x] ~~**Step 1 — i.MX `UART4_RXD` pull-up patch.**~~ **INVALIDATED 2026-05-10.** Authoritative bit encoding from u-boot `arch/arm/include/asm/mach-imx/iomux-v3.h` (IMX8MM branch): `PAD_CTL_PUE = 0x40`, `PAD_CTL_PE = 0x100`. Therefore `0x140 = PE | PUE` — the pad **already has the internal pull-up enabled**. Also: the correct conf_reg physical address is `0x303304B4` (UART4_RXD conf_reg offset 0x4B4 + IOMUXC base 0x30330000), not the previously stated `0x30330280`. No `devmem` patch is needed or warranted.

- [x] **Step 1' — Decisive bring-up test: flash `hello_world.bin`.** **PASSED 2026-05-10.** Captured `LIFETRAC L072 tick=0x0000006D` through `0x00000073` cleanly on `/dev/ttymxc3` @ 19200 8N1 → LPUART1/AF6/PA2 ↔ UART4 hardware path fully functional → bug isolated to production firmware logic.

- [x] **Step 2' — Production firmware bring-up audit + HSI16 fix.** **DONE 2026-05-11.** Root cause: `platform_clock_init_hsi16()` cleared `RCC_CR.HSION` after switching SYSCLK to HSE, but `host_uart_init()` selected HSI16 as the LPUART1 kernel clock via `CCIPR[11:10]=10`. With HSION off, LPUART1's baud-rate generator had no clock → continuous low (`0x00`) on TX. **Fix:** removed the `RCC_CR &= ~RCC_CR_HSION` line in [`hal/platform.c`](firmware/murata_l072/hal/platform.c) `platform_clock_init_hsi16()`, and added a defensive `RCC_CR |= RCC_CR_HSION; while ((RCC_CR & RCC_CR_HSIRDY) == 0U) {}` at the top of [`host/host_uart.c`](firmware/murata_l072/host/host_uart.c) `host_uart_init()`. Build artifact: `build/firmware.bin` = 15 288 bytes (was 15 276; +12 bytes). After flash, captured BOOT_URC (0xF0), READY_URC (0xF2), STATS/FAULT URCs (0xF1), plus ASCII traces `M:RADIO_BYPASS`, `C:SEND_BOOT`, `C:SEND_READY`, `C:INIT_DONE` on `/dev/ttymxc3` @ 921600 8N1.

- [x] **Step 6 — LPUART1 RX bug — CLOSED 2026-05-11 (evening). W1-7 PASSED.** Two fixes landed (IDLE-recovery + `host_uart_poll_dma` vs IRQ race on `RDR`); both ASCII (`ATI`/`AT+VER?`/`AT+STAT?`) and binary (`VER_REQ`/`VER_URC`, `STATS_DUMP_REQ`/`STATS_URC`) paths now roundtrip cleanly with `HOST_PARSE_ERR=0`, `HOST_UART_ERR_LPUART=0`, `HOST_UART_ERR_USART1=0`, all per-flag PE/FE/NE/ORE = 0. Method G probe `rc` dropped from `2` (transport timeout) to `1` (the remaining failure is `[FAIL] sx1276 version reg valid` — a separate radio-SPI issue, not a UART issue). **20-cycle standard quant: 20/20 PASS** (`FINAL_RESULT_PASS=20`, exceeds the ≥18/20 acceptance criterion). Diagnostic `C:NOMATCH` branch removed; build artifact: 16 240 bytes. Authoritative writeup: [`../AI NOTES/2026-05-11_W1-7_RX_Implementation_Plan_Copilot_v1_3.md`](../AI%20NOTES/2026-05-11_W1-7_RX_Implementation_Plan_Copilot_v1_3.md) §11–§12. Historical investigation kept below for posterity.

- [x] **W1-10 Phase A — Single-board RX-liveness probe — CLOSED 2026-05-12 evening.** Added `--probe rx` sub-mode to [`method_h_stage2_tx_probe.py::run_rx_liveness()`](firmware/x8_lora_bootloader_helper/method_h_stage2_tx_probe.py) and wired it through the existing wrapper [`run_method_h_stage2_tx_end_to_end.ps1 -Probe rx`](firmware/x8_lora_bootloader_helper/run_method_h_stage2_tx_end_to_end.ps1). Probe verifies the firmware's LoRa receive chain is alive end-to-end up to the host URC dispatch boundary, **without** requiring a paired transmitter. Seven gates (RegOpMode pre/post == 0x85, RegRssiValue in plausible band, RegRssiValue varies between samples = AGC alive, radio_state == 4 (RX_CONT), host invariants stable, no real FAULT_URC during window). **Bench evidence:** [`bench-evidence/W1-10_rx_liveness_2026-05-11_133459/`](bench-evidence/W1-10_rx_liveness_2026-05-11_133459/) — 7/7 gates PASS first run on Board 2. `RegOpMode(pre)=0x85`, `RegOpMode(post)=0x85`, `RegRssiValue A=-120 dBm B=-119 dBm` (1 LSB AGC twitch on quiet bench noise floor — exactly the Semtech §5.5.5 expectation), `RegModemStat=0x04` (only RxOngoing bit set = idle-but-armed for preamble), `radio_state=4` (RX_CONT), host_parse_err=0, all UART per-flag error counters unchanged, 0 real FAULT_URC across 10 s window (post-VER drain consumed 4 frames per W1-9g `drain_pending()`). Authoritative writeup: [`../AI NOTES/2026-05-12_W1-10_RX_Validation_Plan_Copilot_v1_0.md`](../AI%20NOTES/2026-05-12_W1-10_RX_Validation_Plan_Copilot_v1_0.md). **Next action:** Phase B (W1-10b) two-board end-to-end ≥99% match rate per [BRINGUP_MAX_CARRIER §5 Stage 3](firmware/murata_l072/BRINGUP_MAX_CARRIER.md) — **probe code shipped 2026-05-11 evening**: new `--probe rx_listen` (RX side) and `--probe tx_burst` (TX side) sub-modes in [`method_h_stage2_tx_probe.py`](firmware/x8_lora_bootloader_helper/method_h_stage2_tx_probe.py), orchestrator [`run_w1_10b_rx_pair_end_to_end.ps1`](firmware/x8_lora_bootloader_helper/run_w1_10b_rx_pair_end_to_end.ps1) opens two parallel ADB sessions, correlates by full payload (`W1-10b seq=NNNN <random4hex>`), evaluates B1..B6, writes `summary.json` to `bench-evidence/W1-10b_rx_pair_<stamp>/`. RX-side smoke test 2026-05-11 14:01 PASS (`__W1_10B_LISTEN_DONE__ rx_frames=0 ... real_faults=0 invariants_violated=0 probe_rc=0`); orchestrator pre-flight check gracefully fails when one board absent. Execution recipe in [`../AI NOTES/2026-05-12_W1-10_RX_Validation_Plan_Copilot_v1_0.md`](../AI%20NOTES/2026-05-12_W1-10_RX_Validation_Plan_Copilot_v1_0.md) §3.5. **Blocked on Board 1 (`2D0A1209DABC240B`) returning to the bench**; reflash with Stage 1 helper if it has pre-W1-9d firmware.

- [x] **W1-9g + W1-9b T2 — Post-VER STATS dispatch stall + FSK probe relaxation — CLOSED 2026-05-12.** Root cause was probe-side (no firmware change): after `VER_REQ` returned, the firmware emitted unsolicited `FAULT_URC(HOST_RX_SEEN)` + auto-`STATS_URC(seq=0)` snapshot from `main.c` lines 92/98 (one-shot first-RX-byte diagnostic), and these arrived AFTER `VER_URC` so they got parked in `HostLink.urc_queue`. The next `request(STATS_DUMP_REQ, STATS_URC)` then drained the queued `STATS_URC(seq=0)` snapshots and discarded them as stale type-matches, but the discard loop consumed the entire 1.0 s response window before the actual `STATS_URC(seq=N)` reply could land — verdict `TRANSPORT_FAIL`. Stage 1 didn't hit this because its boot-window `read_frames()` loop explicitly handles every URC type (BOOT/STATS/FAULT/READY/ERR_PROTO) and the per-call print/format work between requests gives a few hundred ms of natural settle. **Fix (probe-side, two functions in [`method_h_stage2_tx_probe.py`](firmware/x8_lora_bootloader_helper/method_h_stage2_tx_probe.py)):** (1) extended `drain_boot()` to handle every URC type explicitly so they don't get parked; (2) added `drain_pending(link, quiet_s=0.25, max_s=1.0)` helper that drains `urc_queue` AND wire interleaved until quiet for 250 ms, called between the `VER_REQ` warm-up and `fetch_stats()`. Plus the previously-landed W1-9b T2 changes in the same probe (pre-state relaxation to accept any LoRa-mode bit-7-set, `VER_REQ` warm-up moved before `fetch_stats`) and the W1-9b/W1-9g `HostLink.request()` rewrite in [`method_g_stage1_probe.py`](firmware/x8_lora_bootloader_helper/method_g_stage1_probe.py) (drain `urc_queue` once up front, then always read wire; discard stale-seq type-matches with logged INFO). **Bench evidence:** [`bench-evidence/W1-9b_fsk_2026-05-11_125612/`](bench-evidence/W1-9b_fsk_2026-05-11_125612/) — `T0b: post-VER drain consumed 4 frames`, `STATS(before) host_parse_err=0`, FSK SLEEP/STDBY transitions execute (`step5 RegOpMode=0x80`, `step8 RegOpMode=0x81` → mode bits 2:0 transition 0→1 = clock alive), `probe_rc=0`. Stage 1 regression check: 3/3 PASS preserved (`bench-evidence/T6_stage1_standard_quant_2026-05-11_125646_*/`). Final FSK verdict `T2_INCONSISTENT` (rather than `FSK_STDBY_WORKS`) is a separate, minor classifier issue: the probe writes `0x00` (FSK SLEEP) but reads back `0x80` (LoRa SLEEP) because per SX1276 datasheet `LongRangeMode` (bit 7) can only toggle from SLEEP — chip silently keeps LoRa mode on the FSK write because it was in `0x85` (LoRa+RXCONTINUOUS) at probe entry. To capture `FSK_STDBY_WORKS` properly the probe would need to pre-walk LoRa→LoRa-SLEEP→FSK-SLEEP — out of scope for the W1-9b/W1-9g closure since the discriminator's actual invariant (mode bits 2:0 transition when commanded) is already proven. Authoritative writeup: [`../AI NOTES/2026-05-12_W1-9g_Post_VER_STATS_Dispatch_Stall_Copilot_v1_0.md`](../AI%20NOTES/2026-05-12_W1-9g_Post_VER_STATS_Dispatch_Stall_Copilot_v1_0.md). **Lessons:** any probe-side `drain_boot()` MUST handle every URC type the firmware can emit out-of-band — unhandled URCs are at best silently iterated past, at worst left in `urc_queue` to poison the next `request()`; tight back-to-back `request(A); request(B);` is fragile when A's response triggers additional unsolicited URCs (always drain between calls, or build a `request_drain()` that explicitly consumes type-mismatches before returning). **Next action:** RX validation milestone (firmware boots into RXCONTINUOUS but no end-to-end packet-receive test exists yet).

- [x] **W1-9f — TX-probe benign FAULT_URC filter — CLOSED 2026-05-12.** First end-to-end TX cycle (after W1-9d/W1-9e) reported gate-fail `[FAIL] no FAULT_URC during cycle` because of one `FAULT_URC code=0x09 sub=0x01 lanes=LPUART1`. Investigation showed fault code `0x09` is **`HOST_FAULT_CODE_HOST_RX_SEEN`** (per `include/host_types.h` and emit site at `main.c` line 91) — a one-shot diagnostic the L072 fires the first time it observes any host byte on a UART lane. NOT `HOST_PARSE_ERROR (0x0B)` as initially mis-labeled in the W1-9e closure note. End-of-cycle `host_parse_err=0` confirmed no parse errors. The probe's `format_fault_payload()` already classifies it correctly (`lanes=LPUART1`), but `wait_for_tx_done()` blindly added every FAULT_URC type to the fault list. **Fix:** added `BENIGN_FAULT_CODES = (HOST_FAULT_CODE_HOST_RX_SEEN, HOST_FAULT_CODE_HOST_DIAG_MARK)` filter in [`firmware/x8_lora_bootloader_helper/method_h_stage2_tx_probe.py`](firmware/x8_lora_bootloader_helper/method_h_stage2_tx_probe.py); benign codes now print as `INFO: diagnostic FAULT_URC during TX wait (benign)` and are excluded from the gate. Real faults (HARDFAULT, NMI, RADIO_*, HOST_PARSE_ERROR, HOST_DMA_OVERRUN, STACK_GUARD, CLOCK_HSE_FAILED, HOST_RX_INACTIVE) still fail the gate. **Result:** W1-9 TX probe **7/7 PASS** (`probe_rc=0`, `TX_DONE_URC tx_id=0x42 status=OK time_on_air_us=18048 tx_power_dbm=14`). Bench evidence: `bench-evidence/W1-9_stage2_tx_2026-05-11_115340/`. Recipe doc [`DESIGN-LORAFIRMWARE/07_Successful_Connection_Recipe_All_Chips_Copilot_v1_0.md`](DESIGN-LORAFIRMWARE/07_Successful_Connection_Recipe_All_Chips_Copilot_v1_0.md) §6 + §7 updated. **Lesson:** when a diagnostic emission shares the same URC type-byte (0xF1 FAULT_URC) as a real fault, host-side gate logic must distinguish by fault-code, not just URC type. **Next action:** relax W1-9b T2 probe pre-state assertion (accept any non-SLEEP LoRa mode); then move to RX validation milestone.

- [x] **W1-9d — PB6 TCXO_VCC enable — IMPLEMENTED & BENCH-CONFIRMED 2026-05-12.** Two-delta firmware change to `hal/platform.c::platform_clock_init_hsi16()`: (D-1) drive **PB6 HIGH** alongside legacy PA12 right after enabling GPIOB clock, before HSE BYPASS probe (powers the TCXO via the ABX00043 R12 0Ω strap); (D-2) **remove the SYSCLK→HSE switch** so the function honors its name (probe HSE for `clock_source_id` reporting only; always keep SYSCLK on HSI16). D-2 was a latent bug only exposed once HSE actually locked: switching SYSCLK 16→32 MHz silently doubled USART1 kernel clock (USART1 uses SYSCLK by default per `RCC_CCIPR[1:0]=00`), halving the 921 600 host transport baud — first probe attempt with D-1-only returned `TRANSPORT_FAIL`. Build: **16 440 B** (was 16 432 B baseline; D-1+SYSCLK-switch attempt was 16 484 B). Stage 1 standard quant **2/2 PASS** post-fix; pre-fix 8-cycle abbreviated run was **7/8 PASS** (one `FAIL_BOOT` cycle inside the broken-baud window). **W1-9b T2 FSK probe verdict moved from `T2_FSK_SLEEP_ONLY` → `PRE_STATE_UNEXPECTED_0x85`** — `RegOpMode=0x85` decodes as **LoRa + RXCONTINUOUS**, meaning the SX1276 successfully exits SLEEP and is actively receiving. The probe just needs its `expected pre-state=0x80 (SLEEP)` assertion relaxed to accept any non-SLEEP LoRa mode (firmware boots straight into LoRa RX now). **W1-10 hardware escalation no longer required — W1-9 OPMODE-stuck root cause was a software/strap mismatch (PA12 vs PB6) compounded by a latent SYSCLK-derived USART1 baud bug, not a missing-clock hardware defect.** Bench evidence: `bench-evidence/T6_stage1_standard_quant_2026-05-11_112444_120-2576/` (Stage 1 PASS) and `bench-evidence/W1-9b_fsk_2026-05-11_112605/` (T2 verdict). Authoritative plan: [`../AI NOTES/2026-05-12_W1-9d_PB6_TCXO_Enable_Plan_Copilot_v1_0.md`](../AI%20NOTES/2026-05-12_W1-9d_PB6_TCXO_Enable_Plan_Copilot_v1_0.md). **Next action:** relax W1-9b T2 probe pre-state assertion (accept any non-SLEEP LoRa mode), then proceed to W1-9 TX bring-up retry now that SX1276 is no longer mode-locked.
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

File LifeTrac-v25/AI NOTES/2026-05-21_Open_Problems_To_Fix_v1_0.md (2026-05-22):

# LifeTrac v25 — Open Problems To Fix

**Date:** 2026-05-21
**Author:** assistant
**Scope:** carry-over work after the 2026-05-20 RF testing plan closed at
the end of Step 5 (matrix + T5b PASS, both opening and closing radio-sleep
audits PASS).
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

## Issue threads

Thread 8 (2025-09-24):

v25 software

dorkmo, 2025-09-24:
Need first draft of joystick remote control over wifi using MQTT. Please use the hardware in the v25 readme. Please create an installation guide .md file.

The tracks will move like tank steering, forward and backward on one valve for each side . the arms go up and down on one solenoid valve. and the bucket goes up and down on one solenoid valve.

The proportional flow control valve will adjust the speed of flow to the whole system. The slowest input from the joystick will set the speed for the entire system. When joysticks are fully engaged the valve will be fully open.

Closed 2025-09-24.

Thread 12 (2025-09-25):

flow valve controller

dorkmo, 2025-09-25:
for v25 we need to add add the Burkert 8605 316532 to the bill of materials https://www.burkert-usa.com/en/products/solenoid-control-valves/controllers/316532
How do we need to update the code?

Closed 2025-09-25.

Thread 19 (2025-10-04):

Integrate DroidPad

dorkmo, 2025-10-04:
> it looks like using https://github.com/UmerCodez/DroidPad will be a better option, the default outputs for the joysticks appear to be values from 1.0 to -1.0 we may need to change the logic on the arduino opta

 _Originally posted by @dorkmo in [#14](https://github.com/OpenSourceEcology/LifeTrac/issues/14#issuecomment-3367974815)_

For version v25, what changes need to be made to allow use of droidpad? What changes to the esp32, ros2 bridge and opta code need to be made to make them all natively interoperable? message command range need to change from 100 to -100 to 1.0 to -1.0 ? What else?

Closed 2025-10-04.

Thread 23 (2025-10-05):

Rasberry Pi Video Feed and Joystick over websocket in browser

dorkmo, 2025-10-05:
in v25, lets create an option for a tractor mounted camera to be connected to a rasberry pi that hosts a websocket or http image feed server that can be accessed from a browser on a phone or a laptop on the network. Next to the image feed will be on screen joysticks that should be able to be controlled by touch or via keyboard shortcuts. We will use the arducam imx335 that uses libcamera. MQTT signals will be sent from the rasberry pi to the opta via the network.

https://www.arducam.com/imx335-camera-module-for-rpi-arducam-opensource-camera.html

https://docs.arducam.com/Raspberry-Pi-Camera/Native-camera/5MP-IMX335

Closed 2025-10-05.

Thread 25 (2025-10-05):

MQTT / OFF / BLE switch for opta

dorkmo, 2025-10-05:
In v25, let's add a hardware switch, a 3 position double throw switch, that will cut off power 12v power to opta in the off position, and select between regular MQTT control or a new option for BLE direct control via the droidpad app. Default to BLE if no switch is installed and the power is on.

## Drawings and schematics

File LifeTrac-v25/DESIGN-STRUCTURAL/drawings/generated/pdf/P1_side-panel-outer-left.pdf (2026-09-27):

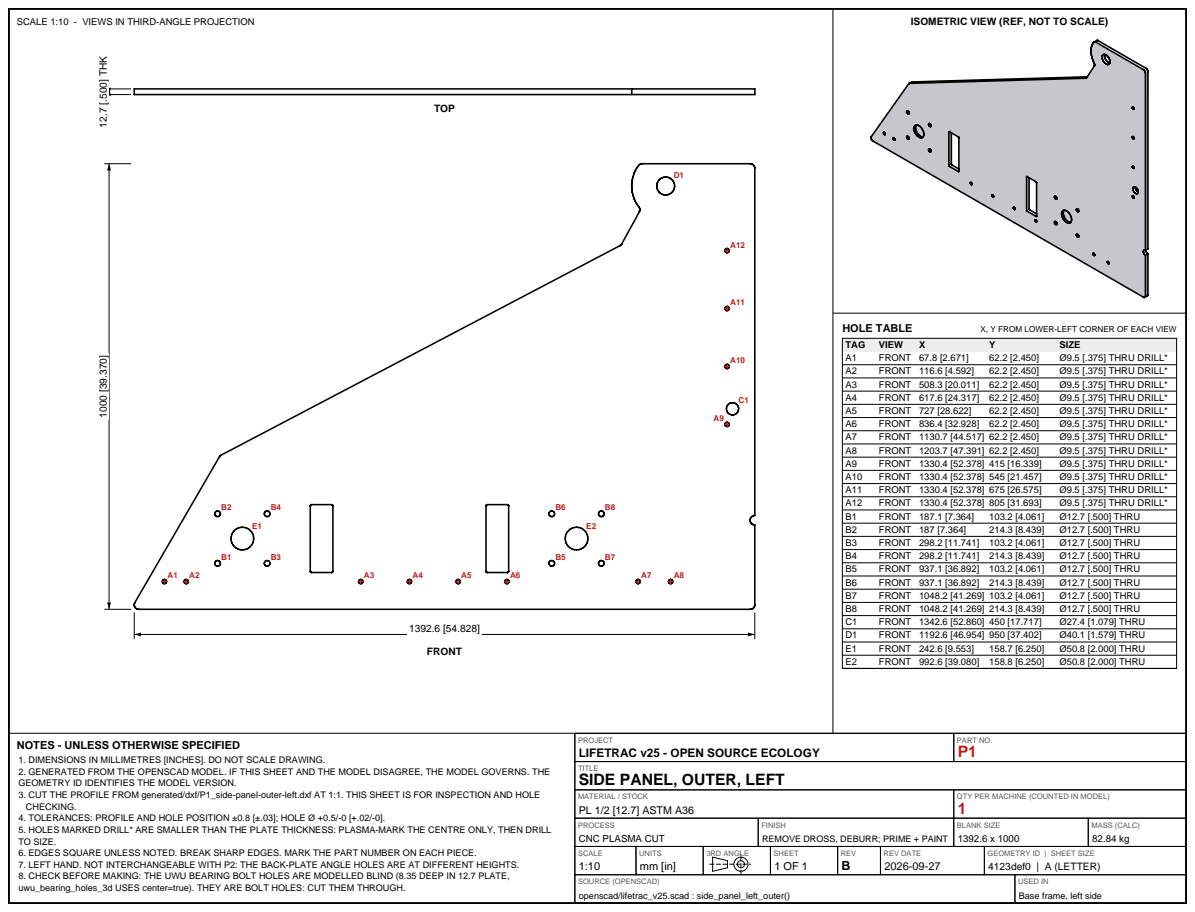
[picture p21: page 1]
PART NO. P1; TITLE; MATERIAL / STOCK PL 1/2 [12.7] ASTM A36; PROCESS CNC PLASMA CUT; BLANK SIZE 1392.6 x 1000; MASS (CALC) 82.84 kg; SCALE 1:10; UNITS mm [in]; 3RD ANGLE; SHEET; REV B; REV DATE 2026-09-27; SOURCE (OPENSCAD) openscad/lifetrac_v25.scad : side_panel_left_outer(); 1000 [39.370] 12.7 [.500] THK; FRONT; TOP; HOLE TABLE; X, Y FROM LOWER-LEFT CORNER OF EACH VIEW; TAG; VIEW; SIZE; FRONT 67.8 [2.671]; Ø9.5 [.375] THRU DRILL*; FRONT 116.6 [4.592]; FRONT 508.3 [20.011] 62.2 [2.450]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

SCALE 1:10 - VIEWS IN THIRD-ANGLE PROJECTION

ISOMETRIC VIEW (REF, NOT TO SCALE)

PROJECT
LIFETRAC v25 - OPEN SOURCE ECOLOGY
SIDE PANEL, OUTER, LEFT

NOTES - UNLESS OTHERWISE SPECIFIED
1. DIMENSIONS IN MILLIMETRES [INCHES]. DO NOT SCALE DRAWING.
2. GENERATED FROM THE OPENSCAD MODEL. IF THIS SHEET AND THE MODEL DISAGREE, THE MODEL GOVERNS. THE
GEOMETRY ID IDENTIFIES THE MODEL VERSION.
3. CUT THE PROFILE FROM generated/dxf/P1_side-panel-outer-left.dxf AT 1:1. THIS SHEET IS FOR INSPECTION AND HOLE
CHECKING.
4. TOLERANCES: PROFILE AND HOLE POSITION ±0.8 [±.03]; HOLE Ø +0.5/-0 [+.02/-0].
5. HOLES MARKED DRILL* ARE SMALLER THAN THE PLATE THICKNESS: PLASMA-MARK THE CENTRE ONLY, THEN DRILL
TO SIZE.
6. EDGES SQUARE UNLESS NOTED. BREAK SHARP EDGES. MARK THE PART NUMBER ON EACH PIECE.
7. LEFT HAND. NOT INTERCHANGEABLE WITH P2: THE BACK-PLATE ANGLE HOLES ARE AT DIFFERENT HEIGHTS.
8. CHECK BEFORE MAKING: THE UWU BEARING BOLT HOLES ARE MODELLED BLIND (8.35 DEEP IN 12.7 PLATE,
uwu_bearing_holes_3d USES center=true). THEY ARE BOLT HOLES: CUT THEM THROUGH.

QTY PER MACHINE (COUNTED IN MODEL)

FINISH
REMOVE DROSS, DEBURR; PRIME + PAINT

GEOMETRY ID | SHEET SIZE
4123def0 | A (LETTER)

USED IN
Base frame, left side

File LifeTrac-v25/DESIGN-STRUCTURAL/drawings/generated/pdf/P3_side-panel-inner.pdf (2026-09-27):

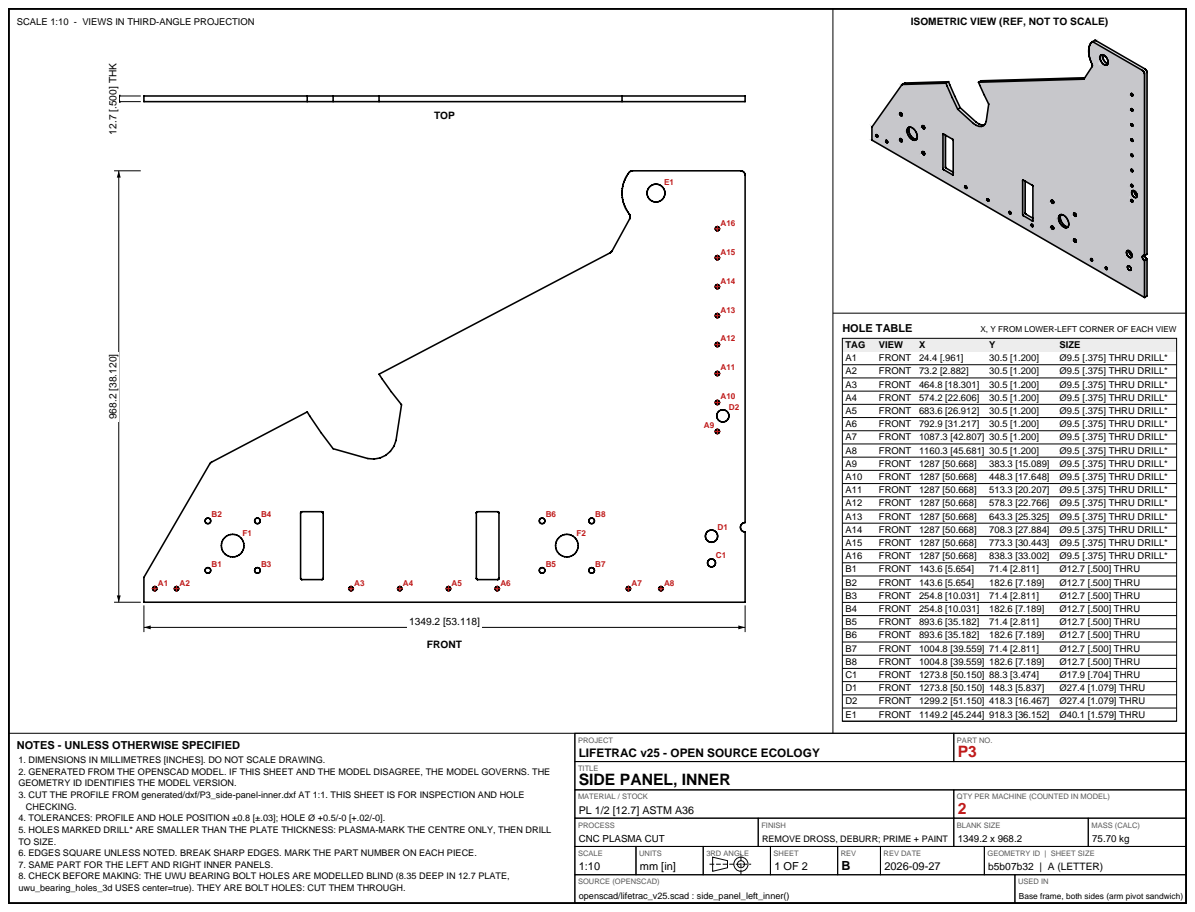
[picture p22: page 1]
PART NO. P3; TITLE; MATERIAL / STOCK PL 1/2 [12.7] ASTM A36; PROCESS CNC PLASMA CUT; BLANK SIZE 1349.2 x 968.2; MASS (CALC) 75.70 kg; SCALE 1:10; UNITS mm [in]; 3RD ANGLE; SHEET; REV B; REV DATE 2026-09-27; SOURCE (OPENSCAD) openscad/lifetrac_v25.scad : side_panel_left_inner(); 968.2 [38.120] 12.7 [.500] THK; FRONT; TOP; HOLE TABLE; X, Y FROM LOWER-LEFT CORNER OF EACH VIEW; TAG; VIEW; SIZE; FRONT 24.4 [.961]; Ø9.5 [.375] THRU DRILL*; FRONT 73.2 [2.882]; FRONT 464.8 [18.301] 30.5 [1.200]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

SCALE 1:10 - VIEWS IN THIRD-ANGLE PROJECTION

ISOMETRIC VIEW (REF, NOT TO SCALE)

PROJECT
LIFETRAC v25 - OPEN SOURCE ECOLOGY
SIDE PANEL, INNER

NOTES - UNLESS OTHERWISE SPECIFIED
1. DIMENSIONS IN MILLIMETRES [INCHES]. DO NOT SCALE DRAWING.
2. GENERATED FROM THE OPENSCAD MODEL. IF THIS SHEET AND THE MODEL DISAGREE, THE MODEL GOVERNS. THE
GEOMETRY ID IDENTIFIES THE MODEL VERSION.
3. CUT THE PROFILE FROM generated/dxf/P3_side-panel-inner.dxf AT 1:1. THIS SHEET IS FOR INSPECTION AND HOLE
CHECKING.
4. TOLERANCES: PROFILE AND HOLE POSITION ±0.8 [±.03]; HOLE Ø +0.5/-0 [+.02/-0].
5. HOLES MARKED DRILL* ARE SMALLER THAN THE PLATE THICKNESS: PLASMA-MARK THE CENTRE ONLY, THEN DRILL
TO SIZE.
6. EDGES SQUARE UNLESS NOTED. BREAK SHARP EDGES. MARK THE PART NUMBER ON EACH PIECE.
7. SAME PART FOR THE LEFT AND RIGHT INNER PANELS.
8. CHECK BEFORE MAKING: THE UWU BEARING BOLT HOLES ARE MODELLED BLIND (8.35 DEEP IN 12.7 PLATE,
uwu_bearing_holes_3d USES center=true). THEY ARE BOLT HOLES: CUT THEM THROUGH.

QTY PER MACHINE (COUNTED IN MODEL)

FINISH
REMOVE DROSS, DEBURR; PRIME + PAINT

GEOMETRY ID | SHEET SIZE
b5b07b32 | A (LETTER)

USED IN
Base frame, both sides (arm pivot sandwich)

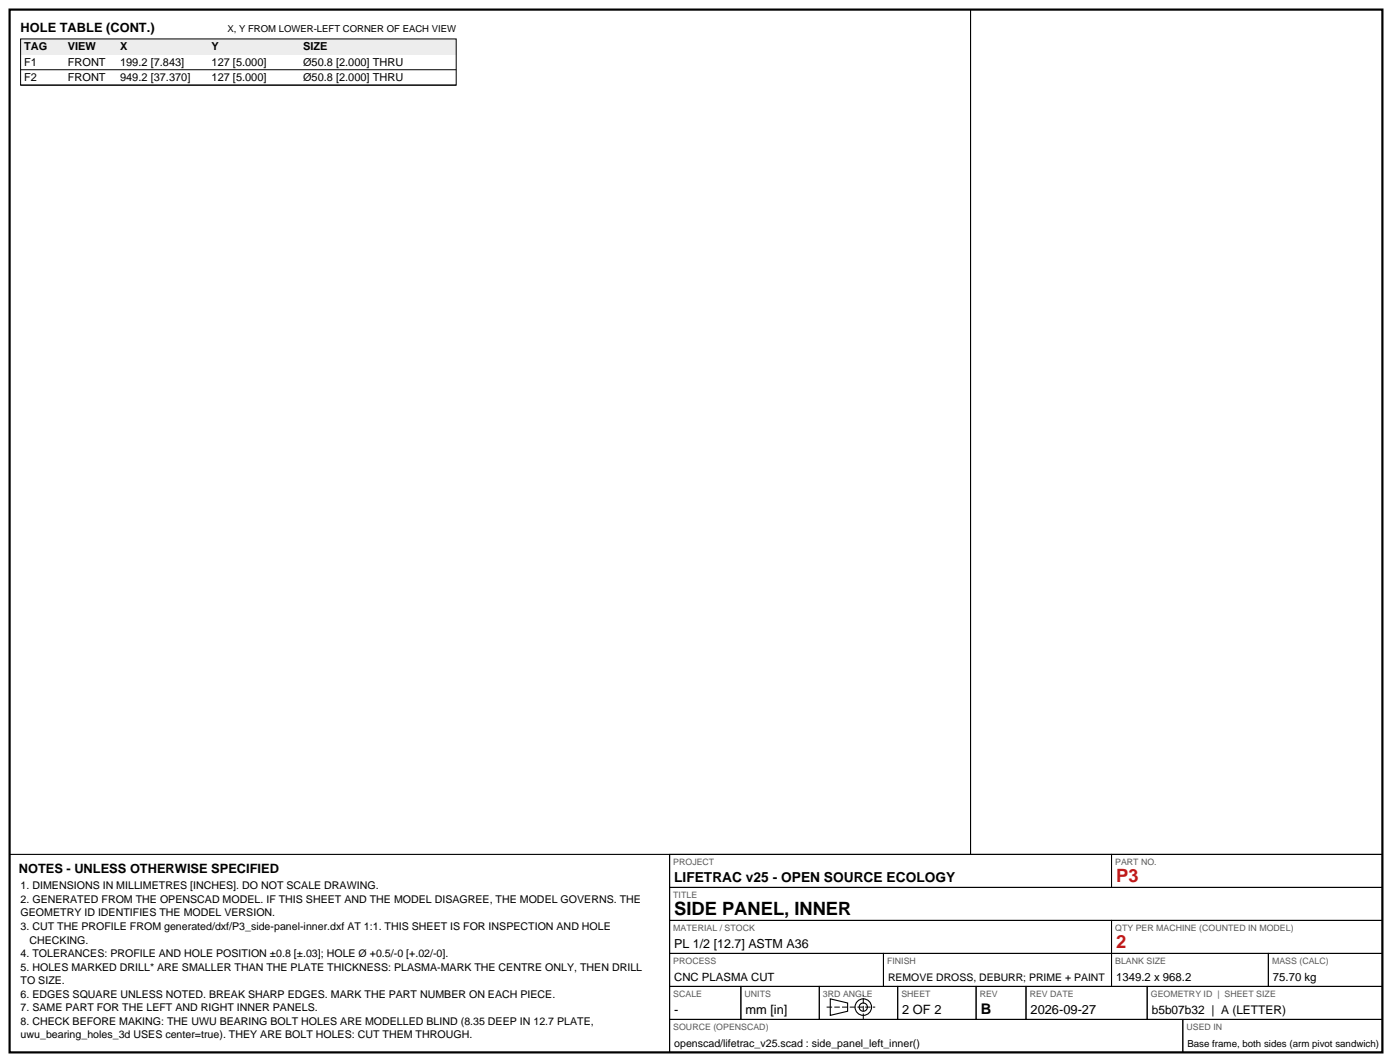
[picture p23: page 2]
PART NO. P3; TITLE; HOLE TABLE (CONT.); X, Y FROM LOWER-LEFT CORNER OF EACH VIEW; TAG; VIEW; SIZE; FRONT 199.2 [7.843]; Ø50.8 [2.000] THRU; FRONT 949.2 [37.370]

PROJECT
LIFETRAC v25 - OPEN SOURCE ECOLOGY
SIDE PANEL, INNER

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

MATERIAL / STOCK PL 1/2 [12.7] ASTM A36 | QTY PER MACHINE (COUNTED IN MODEL) 2

PROCESS CNC PLASMA CUT | FINISH REMOVE DROSS, DEBURR; PRIME + PAINT | BLANK SIZE 1349.2 x 968.2 | MASS (CALC) 75.70 kg

SCALE - | UNITS mm [in] | 3RD ANGLE | | SHEET | REV B | REV DATE 2026-09-27 | GEOMETRY ID | SHEET SIZE b5b07b32 | A (LETTER)

SOURCE (OPENSCAD) openscad/lifetrac_v25.scad : side_panel_left_inner() | USED IN Base frame, both sides (arm pivot sandwich)

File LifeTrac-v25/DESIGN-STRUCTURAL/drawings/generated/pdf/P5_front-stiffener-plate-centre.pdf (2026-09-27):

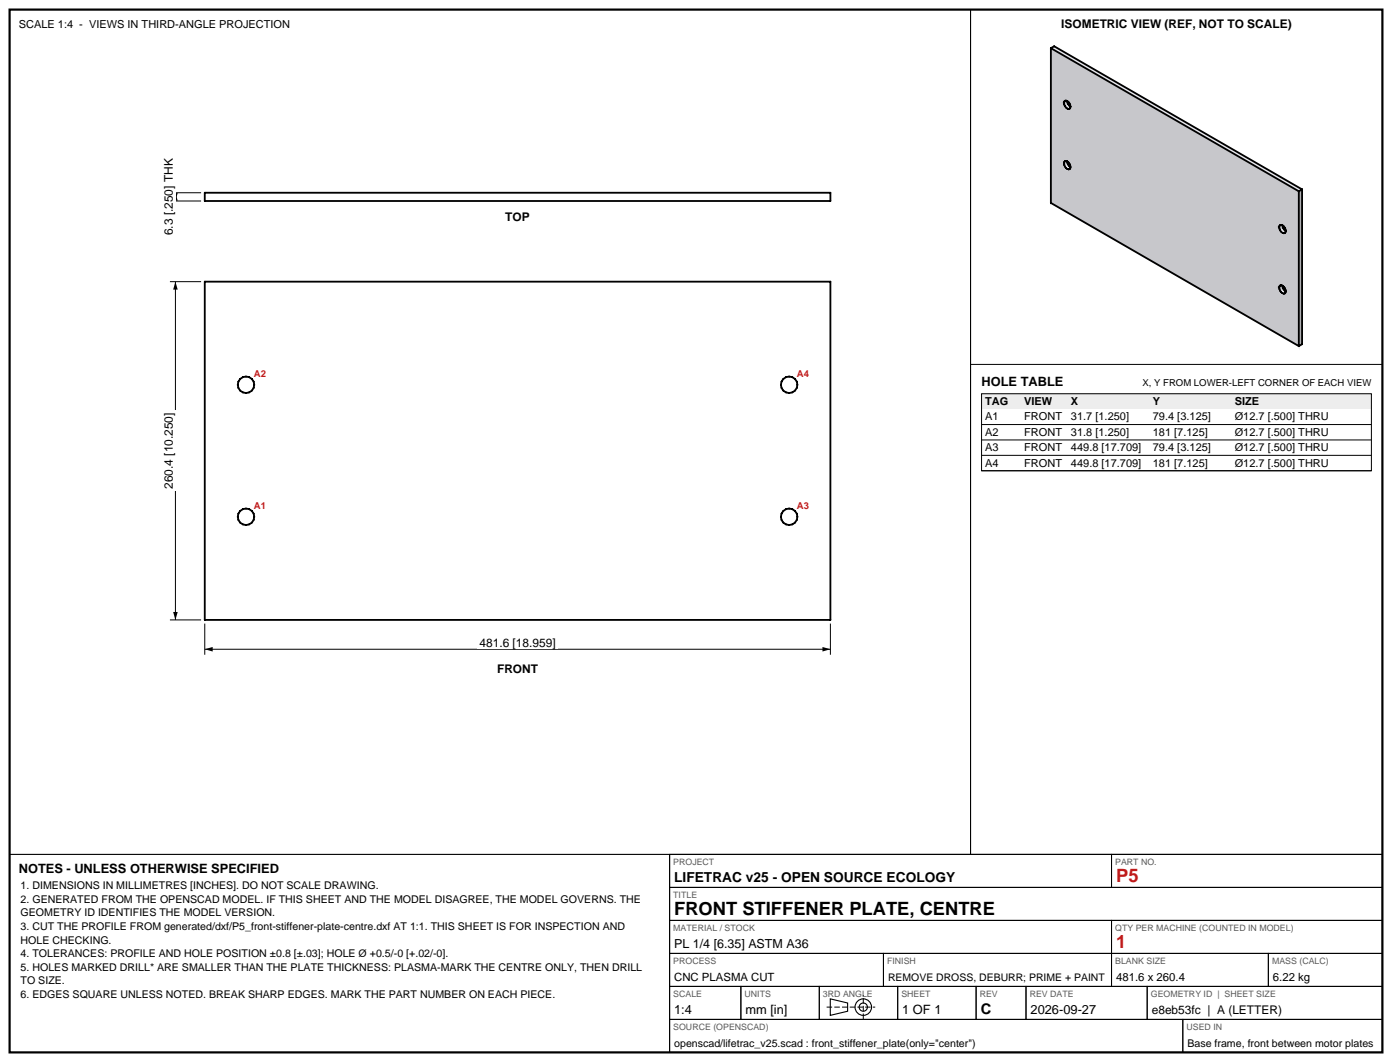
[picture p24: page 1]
PART NO. P5; TITLE; MATERIAL / STOCK PL 1/4 [6.35] ASTM A36; PROCESS CNC PLASMA CUT; BLANK SIZE 481.6 x 260.4; MASS (CALC) 6.22 kg; SCALE 1:4; UNITS mm [in]; 3RD ANGLE; SHEET; REV C; REV DATE 2026-09-27; 260.4 [10.250] 6.3 [.250] THK; FRONT; TOP; HOLE TABLE; X, Y FROM LOWER-LEFT CORNER OF EACH VIEW; TAG; VIEW; SIZE; FRONT 31.7 [1.250]; Ø12.7 [.500] THRU; FRONT 31.8 [1.250]; FRONT 449.8 [17.709] 79.4 [3.125]; FRONT 449.8 [17.709] 181 [7.125]

SCALE 1:4 - VIEWS IN THIRD-ANGLE PROJECTION

ISOMETRIC VIEW (REF, NOT TO SCALE)

PROJECT
LIFETRAC v25 - OPEN SOURCE ECOLOGY
FRONT STIFFENER PLATE, CENTRE

NOTES - UNLESS OTHERWISE SPECIFIED
1. DIMENSIONS IN MILLIMETRES [INCHES]. DO NOT SCALE DRAWING.
2. GENERATED FROM THE OPENSCAD MODEL. IF THIS SHEET AND THE MODEL DISAGREE, THE MODEL GOVERNS. THE
GEOMETRY ID IDENTIFIES THE MODEL VERSION.
3. CUT THE PROFILE FROM generated/dxf/P5_front-stiffener-plate-centre.dxf AT 1:1. THIS SHEET IS FOR INSPECTION AND
HOLE CHECKING.
4. TOLERANCES: PROFILE AND HOLE POSITION ±0.8 [±.03]; HOLE Ø +0.5/-0 [+.02/-0].
5. HOLES MARKED DRILL* ARE SMALLER THAN THE PLATE THICKNESS: PLASMA-MARK THE CENTRE ONLY, THEN DRILL
TO SIZE.
6. EDGES SQUARE UNLESS NOTED. BREAK SHARP EDGES. MARK THE PART NUMBER ON EACH PIECE.

QTY PER MACHINE (COUNTED IN MODEL)

FINISH
REMOVE DROSS, DEBURR; PRIME + PAINT

GEOMETRY ID | SHEET SIZE
e8eb53fc | A (LETTER)

SOURCE (OPENSCAD)
openscad/lifetrac_v25.scad : front_stiffener_plate(only="center")

USED IN
Base frame, front between motor plates

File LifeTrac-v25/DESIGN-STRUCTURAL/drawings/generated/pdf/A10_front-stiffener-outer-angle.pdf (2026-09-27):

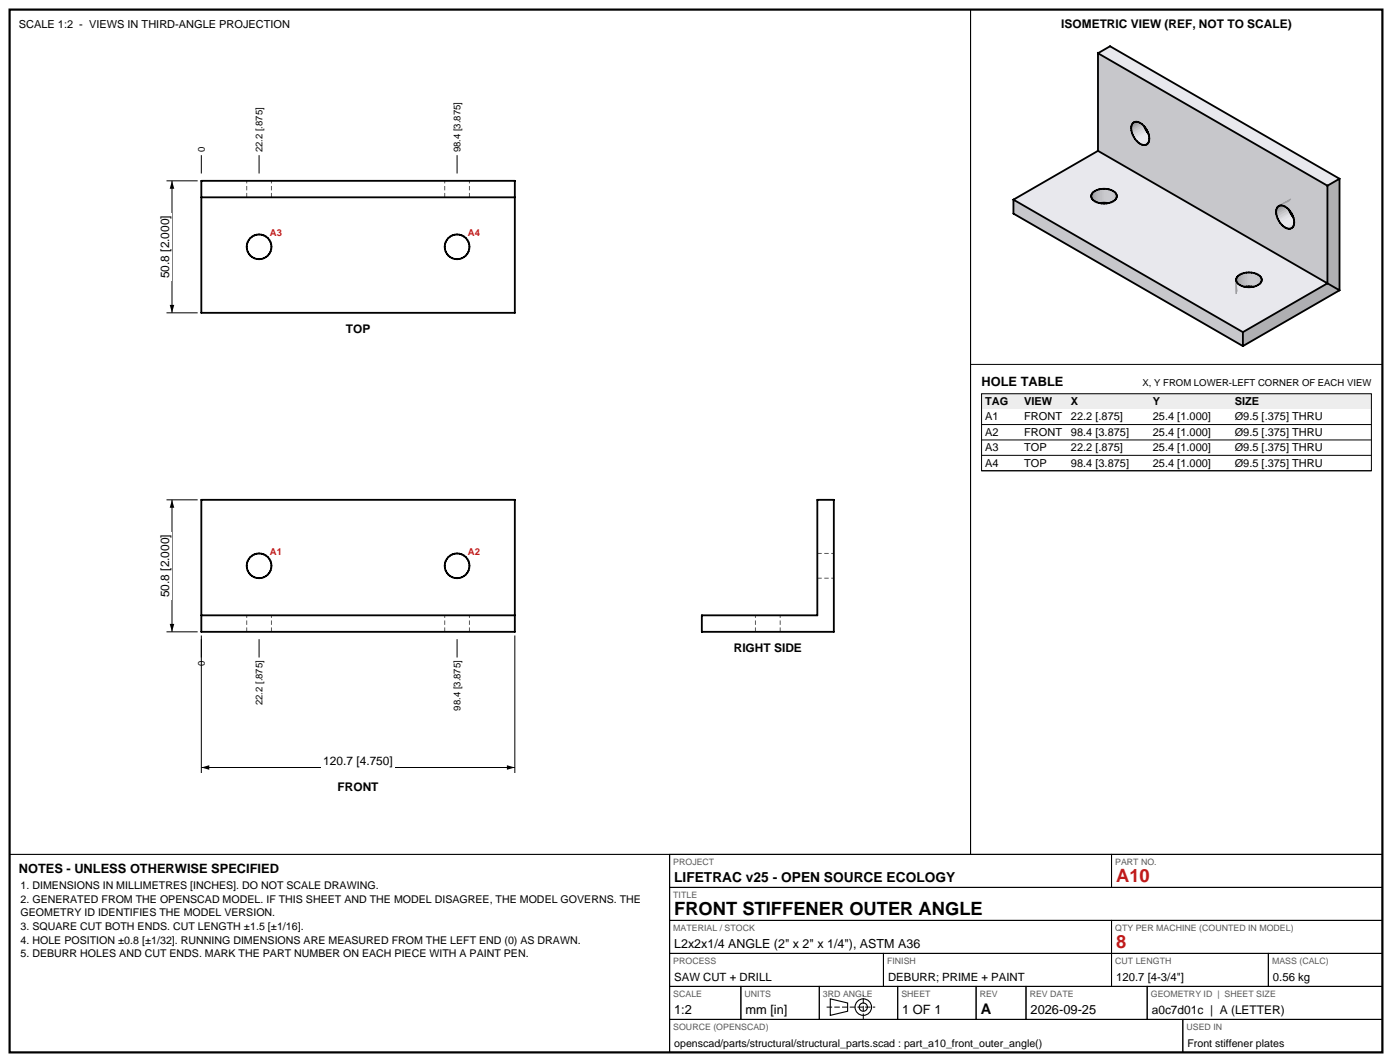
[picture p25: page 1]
PART NO. A10; TITLE; MATERIAL / STOCK L2x2x1/4 ANGLE (2" x 2" x 1/4"), ASTM A36; PROCESS SAW CUT + DRILL; CUT LENGTH 120.7 [4-3/4"]; MASS (CALC) 0.56 kg; SCALE 1:2; UNITS mm [in]; 3RD ANGLE; SHEET; REV A; REV DATE 2026-09-25; FRONT; TOP; RIGHT SIDE; HOLE TABLE; X, Y FROM LOWER-LEFT CORNER OF EACH VIEW; TAG; VIEW; SIZE; FRONT 22.2 [.875]; Ø9.5 [.375] THRU; FRONT 98.4 [3.875]

SCALE 1:2 - VIEWS IN THIRD-ANGLE PROJECTION

ISOMETRIC VIEW (REF, NOT TO SCALE)

PROJECT
LIFETRAC v25 - OPEN SOURCE ECOLOGY
FRONT STIFFENER OUTER ANGLE

NOTES - UNLESS OTHERWISE SPECIFIED
1. DIMENSIONS IN MILLIMETRES [INCHES]. DO NOT SCALE DRAWING.
2. GENERATED FROM THE OPENSCAD MODEL. IF THIS SHEET AND THE MODEL DISAGREE, THE MODEL GOVERNS. THE
GEOMETRY ID IDENTIFIES THE MODEL VERSION.
3. SQUARE CUT BOTH ENDS. CUT LENGTH ±1.5 [±1/16].
4. HOLE POSITION ±0.8 [±1/32]. RUNNING DIMENSIONS ARE MEASURED FROM THE LEFT END (0) AS DRAWN.
5. DEBURR HOLES AND CUT ENDS. MARK THE PART NUMBER ON EACH PIECE WITH A PAINT PEN.

QTY PER MACHINE (COUNTED IN MODEL)

FINISH
DEBURR; PRIME + PAINT

GEOMETRY ID | SHEET SIZE
a0c7d01c | A (LETTER)

SOURCE (OPENSCAD)
openscad/parts/structural/structural_parts.scad : part_a10_front_outer_angle()

USED IN
Front stiffener plates

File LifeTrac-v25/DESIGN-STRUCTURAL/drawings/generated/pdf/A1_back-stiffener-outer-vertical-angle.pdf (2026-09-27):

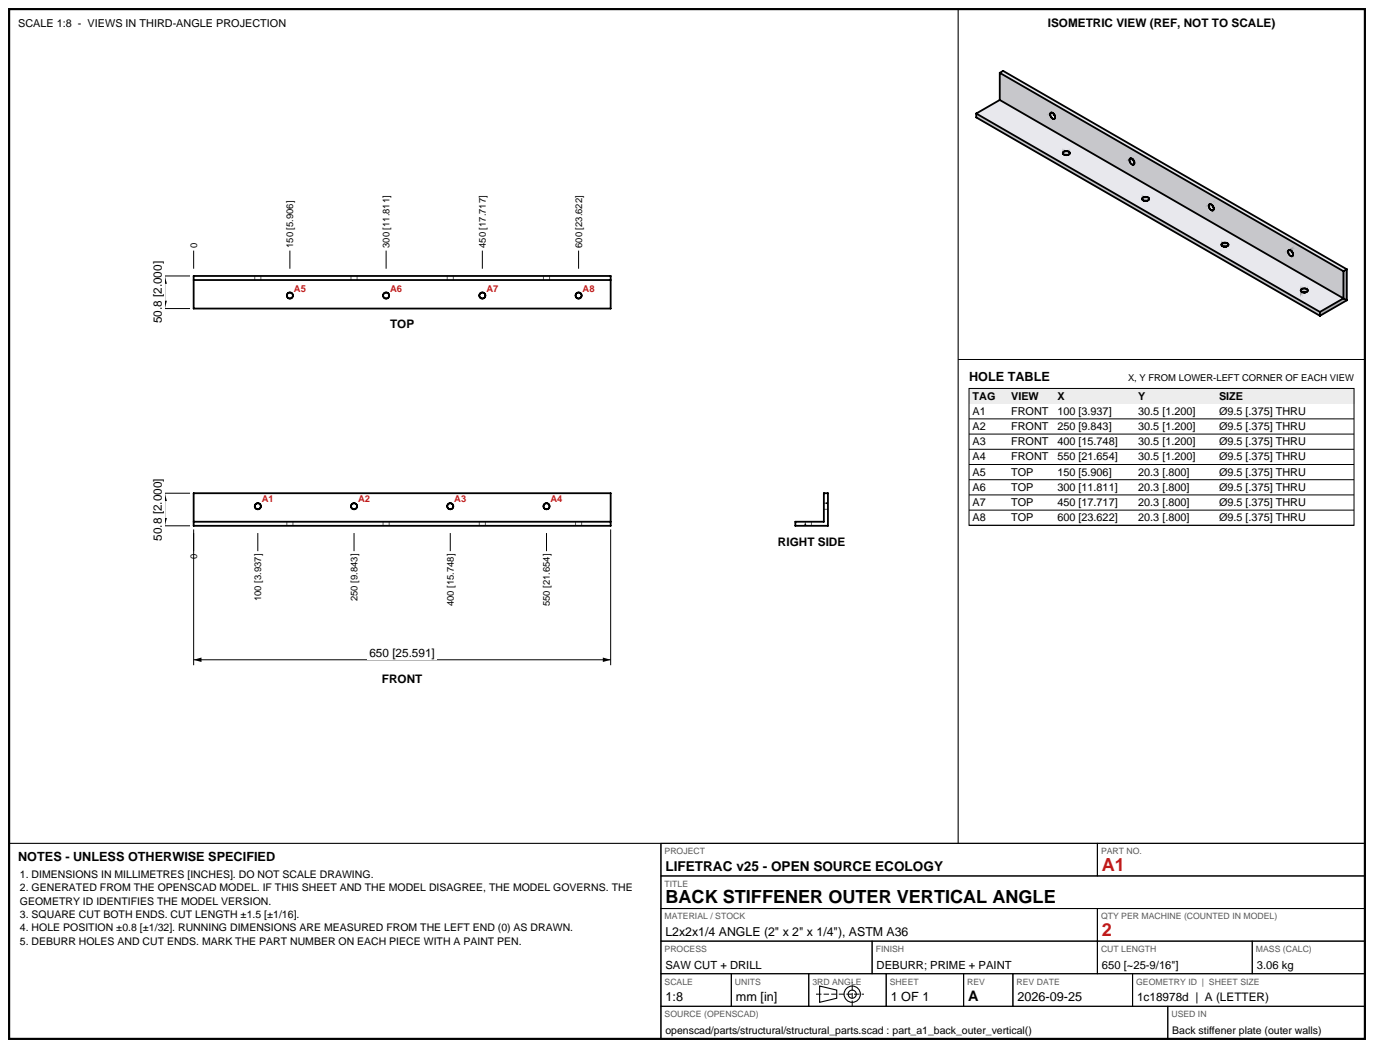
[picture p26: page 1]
PART NO. A1; TITLE; MATERIAL / STOCK L2x2x1/4 ANGLE (2" x 2" x 1/4"), ASTM A36; PROCESS SAW CUT + DRILL; CUT LENGTH 650 [~25-9/16"]; MASS (CALC) 3.06 kg; SCALE 1:8; UNITS mm [in]; 3RD ANGLE; SHEET; REV A; REV DATE 2026-09-25; FRONT; TOP; RIGHT SIDE; HOLE TABLE; X, Y FROM LOWER-LEFT CORNER OF EACH VIEW; TAG; VIEW; SIZE; FRONT 100 [3.937]; Ø9.5 [.375] THRU; FRONT 250 [9.843]; FRONT 400 [15.748]; FRONT 550 [21.654]

SCALE 1:8 - VIEWS IN THIRD-ANGLE PROJECTION

ISOMETRIC VIEW (REF, NOT TO SCALE)

PROJECT
LIFETRAC v25 - OPEN SOURCE ECOLOGY
BACK STIFFENER OUTER VERTICAL ANGLE

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

QTY PER MACHINE (COUNTED IN MODEL)

FINISH
DEBURR; PRIME + PAINT

GEOMETRY ID | SHEET SIZE
1c18978d | A (LETTER)

SOURCE (OPENSCAD)
openscad/parts/structural/structural_parts.scad : part_a1_back_outer_vertical()

USED IN
Back stiffener plate (outer walls)

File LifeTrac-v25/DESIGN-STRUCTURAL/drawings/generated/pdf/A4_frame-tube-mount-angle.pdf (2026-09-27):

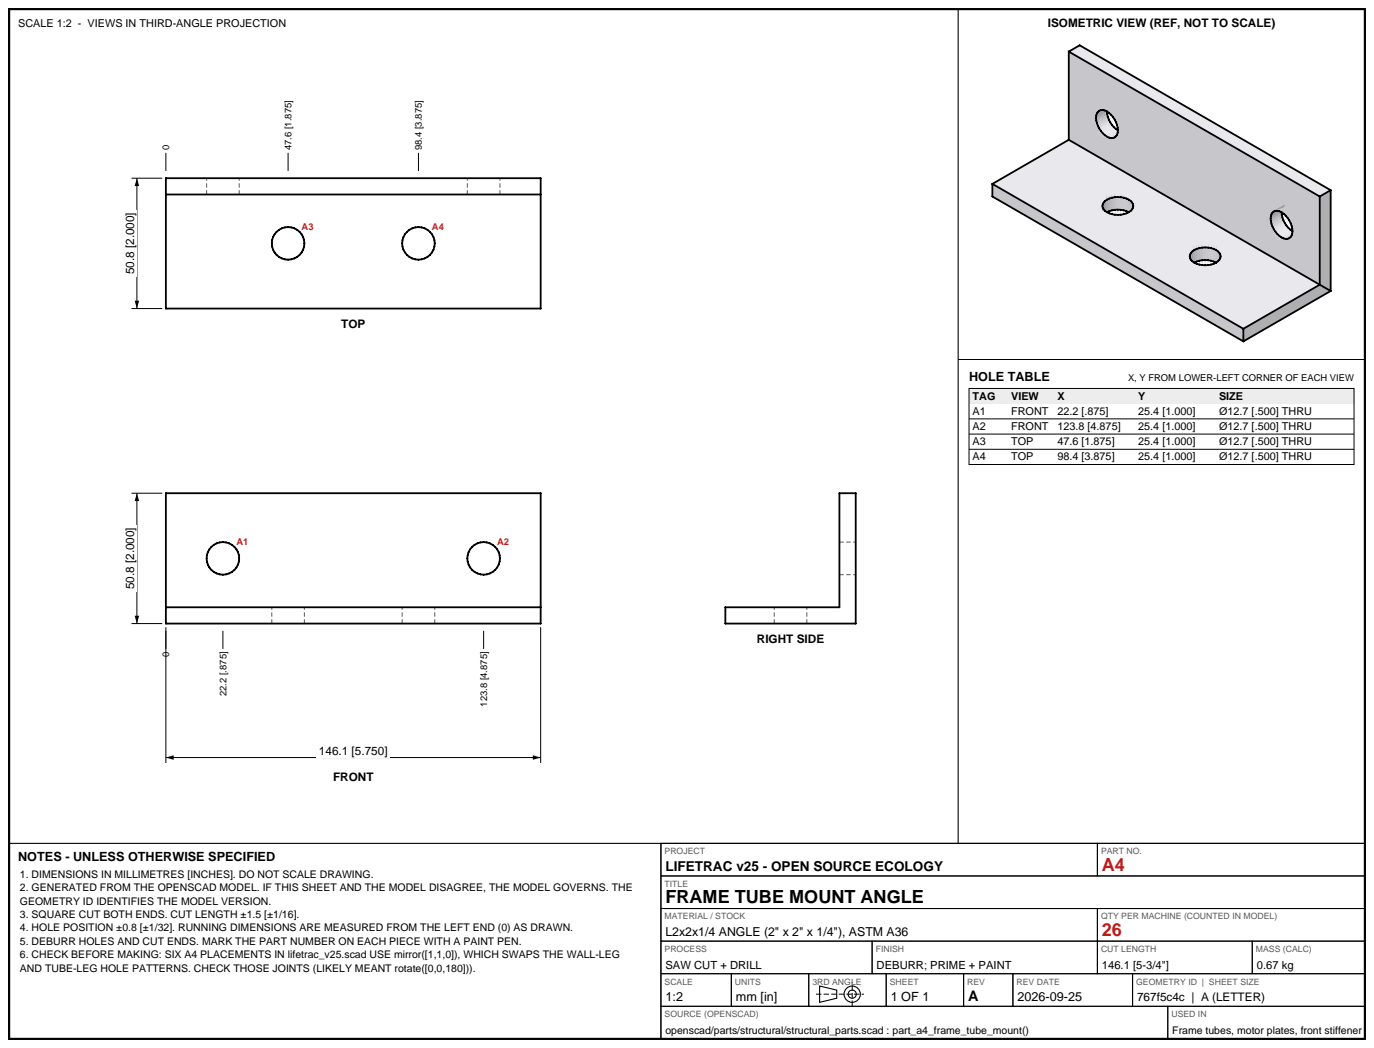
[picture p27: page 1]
PART NO. A4; TITLE; MATERIAL / STOCK L2x2x1/4 ANGLE (2" x 2" x 1/4"), ASTM A36; PROCESS SAW CUT + DRILL; CUT LENGTH 146.1 [5-3/4"]; MASS (CALC) 0.67 kg; SCALE 1:2; UNITS mm [in]; 3RD ANGLE; SHEET; REV A; REV DATE 2026-09-25; FRONT; TOP; RIGHT SIDE; HOLE TABLE; X, Y FROM LOWER-LEFT CORNER OF EACH VIEW; TAG; VIEW; SIZE; FRONT 22.2 [.875]; Ø12.7 [.500] THRU; FRONT 123.8 [4.875]

SCALE 1:2 - VIEWS IN THIRD-ANGLE PROJECTION

ISOMETRIC VIEW (REF, NOT TO SCALE)

PROJECT
LIFETRAC v25 - OPEN SOURCE ECOLOGY
FRAME TUBE MOUNT ANGLE

NOTES - UNLESS OTHERWISE SPECIFIED
1. DIMENSIONS IN MILLIMETRES [INCHES]. DO NOT SCALE DRAWING.
2. GENERATED FROM THE OPENSCAD MODEL. IF THIS SHEET AND THE MODEL DISAGREE, THE MODEL GOVERNS. THE
GEOMETRY ID IDENTIFIES THE MODEL VERSION.
3. SQUARE CUT BOTH ENDS. CUT LENGTH ±1.5 [±1/16].
4. HOLE POSITION ±0.8 [±1/32]. RUNNING DIMENSIONS ARE MEASURED FROM THE LEFT END (0) AS DRAWN.
5. DEBURR HOLES AND CUT ENDS. MARK THE PART NUMBER ON EACH PIECE WITH A PAINT PEN.
6. CHECK BEFORE MAKING: SIX A4 PLACEMENTS IN lifetrac_v25.scad USE mirror([1,1,0]), WHICH SWAPS THE WALL-LEG
AND TUBE-LEG HOLE PATTERNS. CHECK THOSE JOINTS (LIKELY MEANT rotate([0,0,180])).

QTY PER MACHINE (COUNTED IN MODEL)

FINISH
DEBURR; PRIME + PAINT

GEOMETRY ID | SHEET SIZE
767f5c4c | A (LETTER)

SOURCE (OPENSCAD)
openscad/parts/structural/structural_parts.scad : part_a4_frame_tube_mount()

USED IN
Frame tubes, motor plates, front stiffener

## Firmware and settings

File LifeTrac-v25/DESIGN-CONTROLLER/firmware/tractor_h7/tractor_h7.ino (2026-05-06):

// tractor_m7.ino — Portenta H747 M7 core: radio + arbitration + Modbus master.
//
// DRAFT FOR REVIEW. Not compiled or tested.
//
// Runs on the M7 core whether the H747 lives in a standalone Portenta H7 or
// inside a Portenta X8 (binary-compatible — see ARCHITECTURE.md).
//
// Responsibilities:
//   1. Receive LoRa frames from handheld + base + (future) autonomy.
//   2. Validate CRC, decrypt, check sequence (replay protection).
//   3. Run multi-source arbitration loop @ 50 Hz (per LORA_PROTOCOL.md).
//   4. Write the active source's ControlFrame into the Opta over Modbus RTU.
//   5. Tick the Opta watchdog "alive" register at >=10 Hz.
//   6. Read Opta telemetry and emit TelemetryFrames over LoRa @ 1 Hz.
//
// What is NOT here yet (deferred):
//   - Cellular failover, MQTT-SN topic dispatch, video thumbnails.
//   - Per-coil current monitoring, CAN-bus engine telemetry.

#include <Arduino.h>

#if defined(LIFETRAC_USE_METHOD_G_HOST) && (LIFETRAC_USE_METHOD_G_HOST)
#define LIFETRAC_METHOD_G_HOST_BUILD 1
#else
#define LIFETRAC_METHOD_G_HOST_BUILD 0
#endif

#ifndef LIFETRAC_MH_SOFT_BRIDGE
#define LIFETRAC_MH_SOFT_BRIDGE 0
#endif

#ifndef LIFETRAC_MH_SOFT_BRIDGE_HEARTBEAT_MS
#define LIFETRAC_MH_SOFT_BRIDGE_HEARTBEAT_MS 0
#endif

#if !LIFETRAC_METHOD_G_HOST_BUILD
#include <RadioLib.h>
#include <ArduinoRS485.h>
#include <ArduinoModbus.h>
// lora_proto and shared_mem are vendored into ./src/ at build time. CI:
//   .github/workflows/arduino-ci.yml; local: stage_firmware_sketches.ps1.
// The canonical sources still live in firmware/common/. The src/ tree is
// .gitignored.
#include "src/lifetrac_build_config.h"
#include "src/lora_proto/lora_proto.h"
#endif

#if LIFETRAC_METHOD_G_HOST_BUILD
#ifndef LIFETRAC_MH_SERIAL
#error "LIFETRAC_MH_SERIAL must name a HardwareSerial instance when LIFETRAC_USE_METHOD_G_HOST=1"
#endif
#ifndef LIFETRAC_MH_BENCH_LOG
#if LIFETRAC_MH_SOFT_BRIDGE
#define LIFETRAC_MH_BENCH_LOG 0
#else
#define LIFETRAC_MH_BENCH_LOG 1
#endif
#endif
#include "murata_host/mh_runtime.h"
#endif

#if LIFETRAC_METHOD_G_HOST_BUILD && (LIFETRAC_MH_SOFT_BRIDGE)
#if defined(ARDUINO_PORTENTA_X8)
#include <SerialRPC.h>
#ifndef LIFETRAC_MH_BRIDGE_DEBUG_SERIAL
#define LIFETRAC_MH_BRIDGE_DEBUG_SERIAL SerialRPC
#endif
#else
#ifndef LIFETRAC_MH_BRIDGE_DEBUG_SERIAL
#define LIFETRAC_MH_BRIDGE_DEBUG_SERIAL Serial
#endif
#endif
#endif

// Stock PORTENTA_X8 core exposes only Serial1 (SERIAL_HOWMANY=1), but Method G
// bench routing for Max Carrier targets the H7 Serial2 mapping. Provide an
// X8-only Serial2 object so -DLIFETRAC_MH_SERIAL=Serial2 links in this mode.
#if defined(ARDUINO_PORTENTA_X8) && (SERIAL_HOWMANY < 2)
#ifndef SERIAL2_TX
#define SERIAL2_TX PA_15
#endif
#ifndef SERIAL2_RX
#define SERIAL2_RX PF_6
#endif
#ifndef SERIAL2_RTS
#define SERIAL2_RTS PF_8
#endif
#ifndef SERIAL2_CTS
#define SERIAL2_CTS PF_9
#endif
arduino::UART _UART2_(SERIAL2_TX, SERIAL2_RX, SERIAL2_RTS, SERIAL2_CTS);
#endif

// X8 compatibility: the portenta_x8 SDK replaces `Serial` with an ErrorSerialClass
// that requires the SerialRPC library. Redirect all debug output to a no-op sink
// so the same source compiles for both portenta_x8 and envie_m7/portenta_h7_m7.
#if (defined(ARDUINO_PORTENTA_X8) || defined(LIFETRAC_X8_NO_USB_SERIAL)) && !(LIFETRAC_METHOD_G_HOST_BUILD && (LIFETRAC_MH_SOFT_BRIDGE))
namespace { struct _NullSerial {
    void begin(unsigned long) {}
    template<typename T> size_t print(T)   { return 0; }
    template<typename T> size_t println(T) { return 0; }
    size_t println() { return 0; }
} _nullSerial; }
#define Serial _nullSerial
#endif

#if LIFETRAC_METHOD_G_HOST_BUILD && (LIFETRAC_MH_SOFT_BRIDGE)
static void mh_soft_bridge_pump() {
    while (LIFETRAC_MH_SERIAL.available() > 0) {
        int value = LIFETRAC_MH_SERIAL.read();
        if (value < 0) {
            break;
        }
        LIFETRAC_MH_BRIDGE_DEBUG_SERIAL.write((uint8_t)value);
    }

    while (LIFETRAC_MH_BRIDGE_DEBUG_SERIAL.available() > 0) {
        int value = LIFETRAC_MH_BRIDGE_DEBUG_SERIAL.read();
        if (value < 0) {
            break;
        }
        LIFETRAC_MH_SERIAL.write((uint8_t)value);
    }
}
#endif

#if LIFETRAC_METHOD_G_HOST_BUILD && defined(LIFETRAC_MH_BENCH_LOG) && (LIFETRAC_MH_BENCH_LOG)
static void mh_bench_log_sink(const char *line, void *ctx) {
    (void)ctx;
    if (line != nullptr) {
        Serial.println(line);
    }
}
#endif

#if !LIFETRAC_METHOD_G_HOST_BUILD

// Forward declarations for types used in helper-function signatures, so the
// Arduino preprocessor's auto-generated prototypes (inserted near the top of
// the translation unit) can resolve `AxisRamp&` etc. before the full struct
// definitions appear further down. Without these, arduino-cli emits
// "redeclared as different kind of symbol" because the auto-prototype is
// parsed in a scope where the struct name is unknown.
struct AxisRamp;

// ---------- Modbus master over RS-485 (Max Carrier J6) ----------
// 115200 8N1, RTU framing. Opta is slave id 0x01 (per TRACTOR_NODE.md).
#define OPTA_SLAVE_ID 0x01

// Opta register map — SOURCE OF TRUTH is TRACTOR_NODE.md § Modbus RTU register map.
// Holding registers (master writes):
//   0x0000 valve_coils      uint16 bitfield, 8 bits used
//   0x0001 flow_setpoint_1  uint16 (0..10000)
//   0x0002 flow_setpoint_2  uint16 (0..10000)
//   0x0003 aux_outputs      uint16 bitfield (R10-R12 + engine-kill arm)
//   0x0004 watchdog_counter uint16 — must increment >=10 Hz
//   0x0005 command_source   uint16 enum (logging only)
//   0x0006 arm_engine_kill  uint16 non-zero = energize engine-kill solenoid
// Input registers (slave writes, master reads):
//   0x0100 safety_state     uint16 enum
//   0x0101 digital_inputs   uint16 bitfield
//   0x0102..0x0107 analog telemetry block (battery, hyd, coolant, oil, aux)
//   0x0108 relay_fault_flags
//   0x0109..0x010A opta_uptime_s (uint32)
//   0x010B opta_fw_version
enum OptaHolding : uint16_t {
    REG_VALVE_COILS    = 0x0000,
    REG_FLOW_SP_1      = 0x0001,
    REG_FLOW_SP_2      = 0x0002,
    REG_AUX_OUTPUTS    = 0x0003,
    REG_WATCHDOG_CTR   = 0x0004,
    REG_CMD_SOURCE     = 0x0005,
    REG_ARM_ESTOP      = 0x0006,
    HOLDING_BLOCK_LEN  = 7,
};
enum OptaInput : uint16_t {
    REG_SAFETY_STATE   = 0x0100,
    REG_DIGITAL_INPUTS = 0x0101,
    REG_BATTERY_MV     = 0x0102,
    REG_HYD_SUPPLY     = 0x0103,
    REG_HYD_RETURN     = 0x0104,
    REG_COOLANT_C      = 0x0105,
    REG_OIL_C          = 0x0106,
    REG_AUX_ANALOG     = 0x0107,
    REG_RELAY_FAULTS   = 0x0108,
    INPUT_BLOCK_LEN    = 12,
    REG_TELEM_AI_BASE  = REG_BATTERY_MV,   // 6 contiguous analog values
};

// Bit positions inside REG_VALVE_COILS (per TRACTOR_NODE.md).
enum ValveBit : uint16_t {
    VB_DRIVE_LF = 0, VB_DRIVE_LR, VB_DRIVE_RF, VB_DRIVE_RR,
    VB_BOOM_UP, VB_BOOM_DN, VB_BUCKET_CURL, VB_BUCKET_DUMP,
};

// ---------- M4 shared SRAM (mirror of tractor_m4.cpp) ----------
// Layout owned by firmware/common/shared_mem.h. The M4 watchdog trips if we
// don't stamp `alive_tick_ms` AND `loop_counter` every loop iteration.
#include "src/shared_mem.h"
static volatile SharedM7M4* const SHARED =
    reinterpret_cast<volatile SharedM7M4*>(LIFETRAC_SHARED_ADDR);

#if defined(LIFETRAC_BENCH_RADIO_COUNTERS) || defined(LIFETRAC_X8_BOOT_TRACE)
static inline void bench_radio_set(uint32_t index, uint32_t value) {
    if (index < 11u) {
        SHARED->reserved[index] = value;
        __DMB();
    }
}

static inline void bench_radio_add(uint32_t index, uint32_t delta = 1u) {
    if (index < 11u) {
        SHARED->reserved[index] += delta;
        __DMB();
    }
}

static inline void bench_radio_reset() {
    for (uint32_t index = 0; index < 11u; ++index) {
        SHARED->reserved[index] = 0u;
    }
    bench_radio_set(LIFETRAC_SHARED_RADIO_MAGIC_IDX, LIFETRAC_SHARED_RADIO_MAGIC);
}

static inline uint32_t bench_radio_meta(uint8_t source_id, uint8_t frame_type,
                                        int16_t rssi_dbm, int16_t snr_db_x10) {
    return ((uint32_t)source_id) |
           ((uint32_t)frame_type << 8) |
           (((uint32_t)((uint8_t)rssi_dbm)) << 16) |
           (((uint32_t)((uint8_t)snr_db_x10)) << 24);
}

static inline uint32_t bench_radio_status_meta(uint8_t stage, int16_t state) {
    return 0xBA000000u | ((uint32_t)stage << 16) | ((uint16_t)state);
}

static inline uint32_t bench_radio_reg_pack(uint8_t a, uint8_t b, uint8_t c, uint8_t d) {
    return ((uint32_t)a) | ((uint32_t)b << 8) | ((uint32_t)c << 16) | ((uint32_t)d << 24);
}

static inline uint32_t bench_radio_initial_tx_offset_ms() {
    volatile const uint32_t* uid = (volatile const uint32_t*)0x1FF1E800u;
    uint32_t mix = uid[0] ^ (uid[1] << 7) ^ (uid[2] << 13);
    return 100u + (mix % 700u);
}
#else
static inline void bench_radio_set(uint32_t, uint32_t) {}
static inline void bench_radio_add(uint32_t, uint32_t = 1u) {}
static inline void bench_radio_reset() {}
static inline uint32_t bench_radio_meta(uint8_t, uint8_t, int16_t, int16_t) { return 0u; }
static inline uint32_t bench_radio_status_meta(uint8_t, int16_t) { return 0u; }
static inline uint32_t bench_radio_reg_pack(uint8_t, uint8_t, uint8_t, uint8_t) { return 0u; }
static inline uint32_t bench_radio_initial_tx_offset_ms() { return 0u; }
#endif

static inline void boot_trace_mark_raw(uint32_t stage) {
    volatile uint32_t* const shared = reinterpret_cast<volatile uint32_t*>(LIFETRAC_SHARED_ADDR);
    shared[0] = LIFETRAC_SHARED_VERSION;
    shared[1] = stage << 1;
    shared[2] = 0xB0070000u | (stage & 0xFFFFu);
    shared[3] = 0u;
    shared[4] = stage;
}

extern "C" void lifetrac_preinit_marker(void) {
#if defined(LIFETRAC_X8_BOOT_TRACE)
    boot_trace_mark_raw(0xE0u);
#endif
}

__attribute__((section(".preinit_array"), used))
void (*lifetrac_preinit_marker_ptr)(void) = lifetrac_preinit_marker;

extern "C" uint32_t __StackLimit;
extern "C" uint32_t __StackTop;
extern "C" uint32_t __end__;
extern "C" uint32_t mbed_stack_isr_start;
extern "C" uint32_t mbed_stack_isr_size;
extern "C" uint32_t mbed_heap_start;
extern "C" uint32_t mbed_heap_size;
extern "C" void mbed_init(void);
extern "C" void mbed_rtos_start(void);

#if defined(LIFETRAC_X8_ENABLE_LEGACY_OVERRIDES) && (LIFETRAC_X8_ENABLE_LEGACY_OVERRIDES)
extern "C" void software_init_hook(void) {
#if defined(LIFETRAC_X8_BOOT_TRACE)
    boot_trace_mark_raw(0xD0u);
#endif
    mbed_stack_isr_start = reinterpret_cast<uint32_t>(&__StackLimit);
    mbed_stack_isr_size  = reinterpret_cast<uint32_t>(&__StackTop) -
                           reinterpret_cast<uint32_t>(&__StackLimit);
    mbed_heap_start      = reinterpret_cast<uint32_t>(&__end__);
    mbed_heap_size       = reinterpret_cast<uint32_t>(&__StackLimit) -
                           reinterpret_cast<uint32_t>(&__end__);
    mbed_init();
#if defined(LIFETRAC_X8_BOOT_TRACE)
    boot_trace_mark_raw(0xD1u);
#endif
    mbed_rtos_start();
}
#endif /* LIFETRAC_X8_ENABLE_LEGACY_OVERRIDES */

static inline void boot_trace_mark(uint32_t stage) {
#if defined(LIFETRAC_X8_BOOT_TRACE)
    boot_trace_mark_raw(stage);
#else
    (void)stage;
#endif
}

#if defined(ARDUINO_PORTENTA_X8) || defined(LIFETRAC_X8_NO_USB_SERIAL)
static inline void lifetrac_x8_spi_kernel_clock_init() {
    volatile uint32_t* const rcc_cr = reinterpret_cast<volatile uint32_t*>(0x58024400UL);
    volatile uint32_t* const rcc_pllckselr = reinterpret_cast<volatile uint32_t*>(0x58024428UL);
    volatile uint32_t* const rcc_pllcfgr = reinterpret_cast<volatile uint32_t*>(0x5802442CUL);
    volatile uint32_t* const rcc_pll1divr = reinterpret_cast<volatile uint32_t*>(0x58024430UL);
    volatile uint32_t* const rcc_pll1fracr = reinterpret_cast<volatile uint32_t*>(0x58024434UL);
    volatile uint32_t* const rcc_d1ccipr = reinterpret_cast<volatile uint32_t*>(0x5802444CUL);
    volatile uint32_t* const rcc_d2ccip1r = reinterpret_cast<volatile uint32_t*>(0x58024450UL);

    constexpr uint32_t hsion = 1UL << 0;
    constexpr uint32_t hsirdy = 1UL << 2;
    constexpr uint32_t pll1on = 1UL << 24;
    constexpr uint32_t pll1rdy = 1UL << 25;

    if ((*rcc_cr & pll1rdy) == 0) {
        *rcc_cr |= hsion;
        while ((*rcc_cr & hsirdy) == 0) {}

        *rcc_pllckselr = (*rcc_pllckselr & ~((0x3UL << 0) | (0x3FUL << 4))) | (4UL << 4);
        *rcc_pllcfgr = (*rcc_pllcfgr & ~((0x3UL << 2) | (1UL << 1) | (0x7UL << 16))) |
                       (0x2UL << 2) | (0x7UL << 16);
        *rcc_pll1divr = ((24UL - 1UL) << 0) |
                        ((2UL - 1UL) << 9) |
                        ((6UL - 1UL) << 16) |
                        ((2UL - 1UL) << 24);
        *rcc_pll1fracr = 0;
        *rcc_cr |= pll1on;
        while ((*rcc_cr & pll1rdy) == 0) {}
    }

    *rcc_d1ccipr = (*rcc_d1ccipr & ~(0x3UL << 28));
    *rcc_d2ccip1r = (*rcc_d2ccip1r & ~(0x7UL << 12)) | (0x4UL << 12);
}
#else
static inline void lifetrac_x8_spi_kernel_clock_init() {}
#endif

// ---------- LoRa pins (Portenta Max Carrier wires Murata SiP via SPI) ----------
#if defined(ARDUINO_PORTENTA_X8) || defined(LIFETRAC_X8_NO_USB_SERIAL)
class LifeTracX8RadioHal : public ArduinoHal {
  public:
    LifeTracX8RadioHal() : ArduinoHal(SPI, SPISettings(2000000, MSBFIRST, SPI_MODE0)) {}

    void init() override {
        ensureSpiPins();
    }

    void pinMode(uint32_t pin, uint32_t mode) override {
        if (pin == RADIOLIB_NC) {
            return;
        }
        ::pinMode(static_cast<PinName>(pin), static_cast<PinMode>(mode));
    }

    void digitalWrite(uint32_t pin, uint32_t value) override {
        if (pin == RADIOLIB_NC) {
            return;
        }
        ::digitalWrite(static_cast<PinName>(pin), static_cast<PinStatus>(value));
    }

    uint32_t digitalRead(uint32_t pin) override {
        if (pin == RADIOLIB_NC) {
            return 0;
        }
        return (uint32_t)::digitalRead(static_cast<PinName>(pin));
    }

    void spiBeginTransaction() override {
        ensureSpiPins();
    }

    void spiTransfer(uint8_t* out, size_t len, uint8_t* in) override {
        ensureSpiPins();
        for (size_t index = 0; index < len; ++index) {
            uint8_t tx = out ? out[index] : 0xFFu;
            uint8_t rx = 0;
            for (int bit = 7; bit >= 0; --bit) {
                *spiMosi = (tx >> bit) & 0x01u;
                bitDelay();
                *spiSck = 1;
                bitDelay();
                rx = static_cast<uint8_t>((rx << 1) | (spiMiso->read() ? 1u : 0u));
                *spiSck = 0;
                bitDelay();
            }
            if (in) {
                in[index] = rx;
            }
        }
    }

    void spiEndTransaction() override {}

    void term() override {}


    void delay(RadioLibTime_t ms) override {
        busyWaitUs(ms * 1000u);
    }

    void delayMicroseconds(RadioLibTime_t us) override {
        busyWaitUs(us);
    }

    RadioLibTime_t millis() override {
        return (RadioLibTime_t)(tim5Count() / 1000u);
    }

    RadioLibTime_t micros() override {
        return (RadioLibTime_t)tim5Count();
    }
  private:
    void ensureSpiPins() {
        if (!spiSck) {
            spiSck = new mbed::DigitalOut(SPI_SCK, 0);
            spiMosi = new mbed::DigitalOut(SPI_MOSI, 0);
            spiMiso = new mbed::DigitalIn(SPI_MISO);
            spiMiso->mode(PullUp);
        }
    }

    mbed::DigitalOut* spiSck = nullptr;
    mbed::DigitalOut* spiMosi = nullptr;
    mbed::DigitalIn* spiMiso = nullptr;

    static uint32_t tim5Count() {
        return *(volatile uint32_t*)0x40000C24u;
    }

    static void busyWaitUs(RadioLibTime_t us) {
        uint32_t start = tim5Count();
        while ((uint32_t)(tim5Count() - start) < (uint32_t)us) {}
    }

    static void bitDelay() {
        busyWaitUs(1u);
    }
};

static LifeTracX8RadioHal radio_hal;
static Module radio_module(&radio_hal, /*nss*/ PD_4, /*dio0*/ PD_5,
                           /*reset*/ PE_4, /*dio1*/ PE_5);
#else
static Module radio_module(/*nss*/ PD_4, /*dio0*/ PD_5,
                           /*reset*/ PE_4, /*dio1*/ PE_5);
#endif
SX1276 radio(&radio_module);

__attribute__((constructor(101)))
static void boot_trace_constructor_mark() {
    boot_trace_mark(0xE1u);
}

// ---------- pre-shared key ----------
// The fleet key is baked in at compile time from src/lora_proto/key.h, which
// is generated by tools/provision.py. IP-008 halts boot when the key is still
// the all-zero placeholder AND LIFETRAC_USE_REAL_CRYPTO is defined.
#include "src/lora_proto/key.h"
#ifdef LIFETRAC_USE_REAL_CRYPTO
static const uint8_t kFleetKey[16] = LIFETRAC_FLEET_KEY_BYTES;
#else
static const uint8_t kFleetKey[16] = {0};
#endif

static bool fleet_key_is_zero() {
    for (int i = 0; i < 16; i++) if (kFleetKey[i] != 0) return false;
    return true;
}

// ---------- per-source state ----------
struct SourceState {
    uint32_t last_heartbeat_ms;
    uint32_t last_control_ms;
    uint16_t last_sequence;
    uint32_t takectl_until_ms;
    int16_t  rssi_dbm;
    int16_t  snr_db_x10;          // SX1276 reports SNR in 0.25 dB; we store *10
    LpReplayWindow replay;
    ControlFrame latest;
};
static SourceState g_src[3];   // index by source_id - 1

// ---------- FHSS state (DECISIONS.md D-C6, MASTER_PLAN.md §8.17) ----------
//
// Owned here on the M7; the CSMA #ifdef block below feeds them into
// `lp_csma_pick_hop()`. `g_fhss_hop_counter` advances once per TX so
// successive frames land on different channels. `g_fhss_key_id` is the
// fleet hop-key seed (epoch-rotated by `time_service.py` over the X8↔H747
// UART once that service is wired); zero is a valid value during bring-up.
uint32_t g_fhss_hop_counter = 0;
uint32_t g_fhss_key_id      = 0;

// Forward declaration so emit_topic() / send_link_tune() (which appear above
// the definition) can call the CSMA hop helper.
static inline void csma_pick_hop_before_tx();
// IP-104 follow-on: forward-declare so process_air_frame() can hand
// CMD_REQ_KEYFRAME / CMD_CAMERA_SELECT off to the X8 over Serial1.
static void send_cmd_to_x8(uint8_t opcode, const uint8_t* args, uint8_t args_len);

static const uint32_t HEARTBEAT_TIMEOUT_MS = 500;
static const uint32_t CONTROL_TIMEOUT_MS   = 200;   // stale ControlFrame → drop to neutral
static const uint32_t TAKECTL_LATCH_MS     = 30000;

// E-stop latched fault — set by FT_COMMAND/CMD_ESTOP, cleared only by an
// explicit command from the base UI (CMD_CLEAR_ESTOP).
static volatile bool g_estop_latched = false;

// ---------- adaptive SF ladder (R-8 hysteresis) ----------
//
// Per LORA_IMPLEMENTATION.md §3.1 + MASTER_PLAN.md §8.17:
//   - 3 ladder rungs SF7/SF8/SF9, all on BW125 / CR4-5 (control profile).
//   - Step-down (SF↑): require N=3 consecutive bad 5 s windows.
//   - Step-up   (SF↓): require >=30 s clean (6 consecutive good windows).
//   - On transition: send CMD_LINK_TUNE twice back-to-back — once at the old
//     PHY, once at the new PHY — then both ends switch. If no Heartbeat at
//     the new SF within 500 ms, revert and increment the fail counter.
//
// "Bad window" = the *active* source's heartbeat count over the 5 s window
// dropped below 80 % of the expected 50 frames (handheld emits HB @ 10 Hz).
// We track the active source rather than the worst eligible source so that a
// stale autonomy link can't drag the human-driven control link down.
struct LadderRung { uint8_t sf; uint16_t bw_khz; uint8_t cr_den; uint8_t bw_code; };
static const LadderRung LADDER[3] = {
    { 7, 250, 5, 1 },   // bw_code 1 = 250 kHz — fits 20 Hz cadence (DECISIONS.md D-A2)
    { 8, 125, 5, 0 },   // fallback rungs widen back to BW125 for link budget
    { 9, 125, 5, 0 },
};
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
void loop() {
#if LIFETRAC_METHOD_G_HOST_BUILD
#if (LIFETRAC_MH_SOFT_BRIDGE)
#if (LIFETRAC_MH_SOFT_BRIDGE_HEARTBEAT_MS > 0)
    static uint32_t next_hb_ms = 0;
    const uint32_t now_ms = millis();
    if ((int32_t)(now_ms - next_hb_ms) >= 0) {
        next_hb_ms = now_ms + (uint32_t)LIFETRAC_MH_SOFT_BRIDGE_HEARTBEAT_MS;
        LIFETRAC_MH_BRIDGE_DEBUG_SERIAL.println("MH_SOFT_BRIDGE_HB");
    }
#endif
    mh_soft_bridge_pump();
#else
    mh_runtime_loop(millis());
#endif
    return;
#else
    static uint32_t next_arb = 0;
    static uint32_t next_tx  = 0;
    uint32_t now = millis();

    if (next_tx == 0) {
        next_tx = now + bench_radio_initial_tx_offset_ms();
    }

    // Stamp the M4 watchdog FIRST every loop iteration. If we crash anywhere
    // below, the M4 watchdog (200 ms) will pull the PSR-alive GPIO low and
    // dump the valves. Apply this even if nothing else makes progress.
    // Bump version + counter too so the M4 can validate layout and detect
    // a stuck-but-fresh-looking timestamp.
    //
    // IP-105: write under the seqlock convention from shared_mem.h \u2014 raise
    // `seq` to ODD before touching payload, lower to EVEN after. The M4
    // reader retries until it sees a matching pre/post even snapshot.
    SHARED->version       = LIFETRAC_SHARED_VERSION;
    uint32_t s = SHARED->seq;
    SHARED->seq           = s | 1u;          // mark in-progress (odd)
    __DMB();
    SHARED->alive_tick_ms = now;
    SHARED->loop_counter += 1;
    // IP-106: publish the magic constant only when actually latched.
    SHARED->estop_request = g_estop_latched ? LIFETRAC_ESTOP_MAGIC : 0u;
    __DMB();
    SHARED->seq           = (s | 1u) + 1u;   // back to even = "stable"

    poll_radio();
    poll_x8_uart();    // pump KISS frames from gps_service.py / imu_service.py
    poll_link_ladder();  // R-8 hysteresis SF7→SF8→SF9 ladder
    tx_pump(now);      // IP-107: drain the async TX queue, never blocks

    if ((int32_t)(now - next_arb) >= 0) {
        next_arb = now + 50;        // 20 Hz arbitration AND watchdog tick
        apply_control(pick_active_source());   // also advances REG_WATCHDOG_CTR
    }
    if ((int32_t)(now - next_tx) >= 0) {
        next_tx = now + 1000;       // 1 Hz telemetry
        emit_telemetry();
        emit_source_active();       // topic 0x10: link state for the operator UI
    }
#endif
}

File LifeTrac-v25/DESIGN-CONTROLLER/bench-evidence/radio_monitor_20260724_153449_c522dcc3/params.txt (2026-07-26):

git_sha=c522dcc3
duration_s=60
synth_fps=6
synth_budget_b=250
tx_pipeline=v2
tx_serial=2E2C1209DABC240B
rx_serial=2D0A1209DABC240B
host_ip=192.168.1.79
timestamp=20260724_153449

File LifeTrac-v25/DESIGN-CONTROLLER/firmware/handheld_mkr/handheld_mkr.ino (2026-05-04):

// handheld.ino — MKR WAN 1310 handheld controller.
//
// DRAFT FOR REVIEW. Not compiled or tested.
//
// Reads two analog joysticks + 8 buttons + a momentary TAKE CONTROL button +
// a latching E-STOP button, packs a ControlFrame at 20 Hz, and emits a
// Heartbeat at the same cadence. Also receives CMD_LINK_TUNE from the
// tractor (so we follow its adaptive SF ladder) and CMD_ESTOP from any
// peer (so the OLED + LED indicate latched state).
//
// LoRa PHY at boot: SF7 / BW 125 kHz / CR 4/5 / 915 MHz (US) — control
// profile per MASTER_PLAN.md §8.17. The ladder may step us to SF8/SF9.
//
// Expected boards/libs:
//   - Arduino MKR WAN 1310
//   - RadioLib >= 6.x
//   - Adafruit_SSD1306 + Adafruit_GFX (for the optional 128x64 OLED)
//   - lora_proto.h / .c are vendored into ./src/lora_proto/ at build time
//     (CI: see .github/workflows/arduino-ci.yml; local: see
//     LifeTrac-v25/DESIGN-CONTROLLER/tools/stage_firmware_sketches.ps1).
//     The canonical sources still live in firmware/common/lora_proto/.
//     The src/ tree is .gitignored.

#include <Arduino.h>
#include <RadioLib.h>
#include <Wire.h>
#include <Adafruit_SSD1306.h>
#include "src/lora_proto/lora_proto.h"

// ---------- pins ----------
#define PIN_LH_X        A0
#define PIN_LH_Y        A1
#define PIN_RH_X        A2
#define PIN_RH_Y        A3
#define PIN_BTN_BASE    2     // first of 8 contiguous button pins
#define PIN_BTN_TAKECTL 10    // momentary, latched in software for 30 s after release
#define PIN_BTN_ESTOP   11    // latching mushroom — LOW = pressed (latched)
#define PIN_LED_LINK    LED_BUILTIN
#define PIN_LED_ESTOP   12    // panel LED: solid red when E-stop latched

// ---------- LoRa modem ----------
// MKR WAN 1310 wires the Murata SiP to: NSS=LORA_IRQ_DUMB, IRQ=LORA_IRQ, RST=-1, GPIO=LORA_BOOT0.
// (See RadioLib's MKRWAN_1310 example for the canonical pin map.)
SX1276 radio = new Module(LORA_IRQ_DUMB, LORA_IRQ, LORA_RESET, LORA_BOOT0);

// ---------- pre-shared key (PROVISIONED ELSEWHERE — placeholder all-zero) ----------
// IP-008: production builds MUST replace this with the provisioned 16 bytes.
// `setup()` halts at boot if the key is still all zero AND real crypto is on,
// so accidentally flashing the example image cannot ship an unauthenticated link.
static const uint8_t kFleetKey[16] = {0};

static bool fleet_key_is_zero() {
    for (int i = 0; i < 16; i++) if (kFleetKey[i] != 0) return false;
    return true;
}

// ---------- state ----------
static uint16_t g_seq = 0;
static uint8_t  g_hb  = 0;
static uint32_t g_takectl_release_ms = 0;  // 0 = not latched
// Set true on inbound CMD_ESTOP from any peer; cleared only by an explicit
// CMD_CLEAR_ESTOP from BASE.
static bool     g_estop_remote_latched = false;

// FHSS counters — definitions for the externs referenced inside `send_frame()`'s
// LIFETRAC_FHSS_ENABLED block. File-scope (not static) so a future shared
// header could re-extern them without breaking the link.
uint32_t g_fhss_hop_counter = 0;
uint32_t g_fhss_key_id      = 0;
// Last RSSI we observed on any inbound frame — surfaced on the OLED so the
// operator can sanity-check link health before reaching for the cab.
static int16_t  g_last_rx_rssi_dbm = -128;
// IP-307: timestamp of the last successfully decoded inbound frame. Used
// to drive the OLED "NO LINK" boundary indicator so the operator can
// tell the difference between a healthy quiet link and a dead one
// (where ``g_last_rx_rssi_dbm`` would otherwise still display its last
// known value forever).
static uint32_t g_last_rx_ms       = 0;
static const uint32_t LINK_STALE_MS = 3000;   // ~3× the slowest HB period
// Per-source replay window. We only ever receive from tractor + base on the
// handheld, but sizing for 3 sources keeps the index calculus identical to
// tractor_m7.ino so the same lp_replay_check_and_update() call works.
static LpReplayWindow g_replay[3];

static const uint32_t TAKECTL_LATCH_MS = 30000;
static const uint32_t TICK_PERIOD_MS   = 50;   // 20 Hz

// ---------- adaptive SF ladder rung tracking ----------
// Mirrors the LADDER[] table in tractor_m7.ino so an inbound CMD_LINK_TUNE
// can map (sf, bw_code) back to a rung index for state + UI purposes.
struct LadderRung { uint8_t sf; uint16_t bw_khz; uint8_t cr_den; uint8_t bw_code; };
static const LadderRung LADDER[3] = {
    { 7, 250, 5, 1 },   // DECISIONS.md D-A2
    { 8, 125, 5, 0 },
    { 9, 125, 5, 0 },
};
static uint8_t g_ladder_rung = 0;

// ---------- KISS decoder for incoming bytes ----------
static KissDecoder g_dec;

// ---------- OLED (optional; init failure is non-fatal) ----------
#define OLED_W 128
#define OLED_H 64
#define OLED_ADDR 0x3C
static Adafruit_SSD1306 g_oled(OLED_W, OLED_H, &Wire, /*reset*/ -1);
static bool g_oled_ok = false;
static uint32_t g_next_oled_ms = 0;

// ---------- helpers ----------
// Per-axis deadband (counts on the 0..1023 ADC). Keeps neutral truly neutral.
static const int AXIS_DEADBAND = 16;

static int8_t read_axis(int pin) {
    int raw = analogRead(pin);            // 0..1023
    int centered = raw - 512;             // -512..+511
    if (centered > -AXIS_DEADBAND && centered < AXIS_DEADBAND) return 0;
    // Stretch the live region (deadband..511) back to (0..127) so we don't lose range.
    int sign = centered < 0 ? -1 : 1;
    int mag  = (centered < 0 ? -centered : centered) - AXIS_DEADBAND;
    long scaled = (long)mag * 127 / (512 - AXIS_DEADBAND);
    if (scaled > 127) scaled = 127;
    return (int8_t)(sign * scaled);
}

// Per-button debounce — require the same level for >= DEBOUNCE_MS before
// reporting it. Cheap shift-register style filter so we don't allocate.
static const uint32_t DEBOUNCE_MS = 15;
static uint8_t  s_btn_state    = 0;       // currently reported (debounced) state
static uint8_t  s_btn_candidate = 0;      // last raw read
static uint32_t s_btn_change_ms = 0;

static uint16_t read_buttons() {
    uint8_t raw = 0;
    for (int i = 0; i < 8; i++) {
        if (digitalRead(PIN_BTN_BASE + i) == LOW) raw |= (1u << i);
    }
    uint32_t now = millis();
    if (raw != s_btn_candidate) {
        s_btn_candidate = raw;
        s_btn_change_ms = now;
    } else if ((now - s_btn_change_ms) >= DEBOUNCE_MS) {
        s_btn_state = raw;
    }
    return (uint16_t)s_btn_state;
}

// Build a 12-byte AES-GCM nonce: [source_id | seq(LE) | t_seconds(LE) | rand(5)]
// Identical layout to base_station/lora_proto.py build_nonce().
static void build_nonce(uint8_t out[12], uint16_t seq) {
    out[0] = SRC_HANDHELD;
    out[1] = (uint8_t)(seq & 0xFF);
    out[2] = (uint8_t)(seq >> 8);
    uint32_t t = millis() / 1000;
    out[3] = (uint8_t)(t      ); out[4] = (uint8_t)(t >>  8);
    out[5] = (uint8_t)(t >> 16); out[6] = (uint8_t)(t >> 24);
    for (int i = 0; i < 5; i++) out[7 + i] = (uint8_t)random(0, 256);
}
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

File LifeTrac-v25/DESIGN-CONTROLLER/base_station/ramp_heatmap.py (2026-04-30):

"""Round 53 / K-E2: web UI ramp-state heatmap data model.

Operator-visible "why did my stop feel mushy" \u2014 a per-axis,
per-tick classification of the relationship between the operator's
stick intent (``raw``) and the post-ramp value the firmware actually
asserts on the coils (``effective``). Roadmap entry K-E2.

This module is **pure data transformation**. It does not own the
firmware ramp math (see
[tests/test_axis_ramp_sil.py](tests/test_axis_ramp_sil.py) for the
canonical mirror) and it does not render anything on its own \u2014
the web UI consumes the JSON-serializable rows produced by
:func:`build_heatmap` and paints them as a side-by-side raw / effective
bar with a per-tick state-coloured underlay.

Five classification states, in precedence order:

* ``"idle"`` \u2014 both ``raw`` and ``effective`` are within the
  deadband. The axis is at rest; nothing to display.
* ``"matched"`` \u2014 ``|raw - effective| <= deadband``. The
  effective bar tracks the operator one-for-one (steady-state
  pass-through, BC-21 mix-then-ramp at the asymptote).
* ``"reversal"`` \u2014 ``raw`` and ``effective`` are both outside
  the deadband but have opposite signs. The BC-22 reversal-brake
  decay is in flight; the lag is *expected* and the operator
  should see a clear "stop first" indication, not a mushiness flag.
* ``"decay"`` \u2014 ``raw`` is within the deadband but ``|effective|``
  is outside it. A release ramp is in flight (BC-21 / K-A4).
  Same-sign lag with the operator commanding stop.
* ``"mushy"`` \u2014 same-sign lag where ``|raw - effective| >
  mushy_threshold``. The effective value is trailing the raw command
  by more than the operator should feel comfortable with. This is
  the cell the operator is meant to *see* in the heatmap.

The default ``deadband`` mirrors the firmware ``AXIS_DEADBAND`` (BC-29
``ui.axis_deadband`` leaf, default 13). The default
``mushy_threshold`` of 40 (\u2248 31% of int8 full scale) is a
conservative starting point intended to catch obvious lag without
flagging every BC-26 S-curve release.

Pure stdlib; safe to import from web_ui.py.
"""

from __future__ import annotations

from dataclasses import dataclass
from typing import Iterable

# Identity defaults: these mirror firmware constants. Both are
# overridable per-call so a build that widens BC-29 ui.axis_deadband
# can pass the wider value through without recompiling this module.
DEFAULT_DEADBAND = 13
DEFAULT_MUSHY_THRESHOLD = 40

# Public state vocabulary. Pinned by the SIL so a regression that
# silently renames a state trips here.
STATES = ("idle", "matched", "reversal", "decay", "mushy")
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

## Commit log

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2025-10-06 Add BLE safety improvements: fallback on init failure and data length validation
    [lifetrac_v25_controller.ino]
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2025-10-06 Add robust error handling for BLE fallback and fix lastCommandTime update logic
    [lifetrac_v25_controller.ino]
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2025-10-08 Fix documentation and extract duplicate track speed calculation
    - Clarify that zero-radius turning works in both modes (with different power characteristics)
    - Extract computeTrackSpeeds() helper to avoid code duplication
    - Update FLOW_VALVE_CONFIGURATION.md and QUICK_REFERENCE_FLOW_VALVES.md
    - Update FLOW_VALVE_DIAGRAM.md to clarify zero-radius turning behavior
    [lifetrac_v25_controller.ino]
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2025-10-08 Fix jumper logic to use INPUT_PULLUP for proper detection
    - Changed from INPUT_PULLDOWN to INPUT_PULLUP
    - Inverted logic: LOW (jumper to GND) = TWO_VALVES, HIGH (no jumper) = ONE_VALVE
    - Fixed hardware issue where both no-jumper and jumper-to-GND read LOW with pulldown
    - Updated all documentation to reflect correct pin states
    - Updated serial debugging output examples
    [lifetrac_v25_controller.ino]
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2025-12-07 Major parametric and structural design overhaul
    Comprehensive geometry fixes, parametric calculations, and parts standardization were implemented for the LifeTrac v25 loader. Fastener rendering modules were added, and detailed engineering calculations for lifting capacity and structural adequacy are now included and output via echo statements. Documentation for custom fabricated parts and structural analysis was created, and the OpenSCAD model now supports parametric scaling and outputs pass/fail status for all major mechanical checks.
    [lifetrac_v25.scad]
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2025-12-09 Improve hydraulic cylinder and animation logic
    Refactored hydraulic_cylinder module to support total mount-to-mount length and improved extension clamping for realistic visuals. Updated animation logic for arms and bucket to use a looping phase for smoother motion. Fixed orientation and placement of cylinder pins and wheel rotation axes. Adjusted bucket cylinder lug positions for better alignment with cylinder mounts.
    [hydraulics.scad, lifetrac_v25.scad]
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2025-12-12 Add vertical stiffener plates and panel cutouts
    Introduces modules for vertical stiffener plates and associated angle irons, including hole patterns and mounting logic. Updates side panel modules to subtract stiffener holes and trim inner panels for stiffener clearance. Integrates stiffener plates into the base frame assembly for improved structural rigidity.
    [lifetrac_v25.scad]
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2025-12-13 Refine lift cylinder mount calculations and panel holes
    Updated lift cylinder base Y and Z calculations in lifetrac_v25_params.scad for improved leverage and axle clearance, using a more precise geometric approach. Modified side_panel.scad to place the lift cylinder base mount hole on both inner and outer panels, aligning its position with the new world coordinates.
    [lifetrac_v25_params.scad, side_panel.scad]
2025-12-13 Refactor lift cylinder mount calculations for leverage
    Reworked the lift cylinder base Y and Z position calculations to optimize leverage at the lowest arm position. The new approach computes attachment points based on arm geometry, axle clearance, and desired cylinder angle, improving clarity and maintainability.
    [lifetrac_v25.scad]
2025-12-13 Add engine model and stability analysis to loader
    Introduced a parametric engine model and its placement in the assembly. Added a comprehensive weight distribution and stability analysis module, including center of gravity and tipping load calculations. Updated wheel assembly logic for improved rear wheel placement and included new engine and analysis parameters in the configuration file.
    [lifetrac_v25.scad, lifetrac_v25_params.scad]
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2025-12-27 Add folding operator platform with parametric design
    Replaces the fixed standing deck with a 5-component folding platform system, including new parametric OpenSCAD modules for the deck plate, pivot brackets, and angle iron arms. Updates the BOM, CNC layout, and all relevant assemblies to support the folding platform, adds export files for CNC cutting, and integrates pivot and lock pin holes into the frame and side panels. Legacy standing deck files are deprecated and redirected for backward compatibility.
    [cnclayout.scad, export_platform_deck.scad, export_platform_pivot_bracket.scad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]
2025-12-27 Refactor folding platform arm angle iron modeling
    Replaces the for-loop approach with explicit left and right side angle iron modeling for the folding platform arms. Improves parametric positioning, clarifies orientation, and ensures correct mirroring and alignment with pivot plates. Also updates deck translation to sit properly on angle iron legs.
    [lifetrac_v25.scad]
2025-12-27 Refactor folding platform angle iron and pivot bracket
    Extracted platform_angle_iron() module for reuse and simplified bolt hole placement in lifetrac_v25.scad. Redesigned platform_pivot_bracket.scad to use a more parametric L-shape with updated hole positions and geometry for improved clarity and assembly alignment.
    [lifetrac_v25.scad, platform_pivot_bracket.scad]
2025-12-27 Refine platform deck and pivot bracket dimensions
    Updated platform width calculation to use a fixed gap and clarified parameter organization in lifetrac_v25_params.scad. Adjusted pivot bracket extension in platform_pivot_bracket.scad to align with PLATFORM_ARM_LENGTH for improved fit.
    [lifetrac_v25_params.scad, platform_pivot_bracket.scad]
2025-12-27 Adjust platform arm and deck dimensions for bracket width
    Updated calculations for platform arm length and deck depth to account for half the pivot bracket width. Modified related translations and extrusions in SCAD files to ensure correct assembly alignment.
    [lifetrac_v25.scad, lifetrac_v25_params.scad, platform_angle_arm.scad]
2025-12-27 Add transverse angles to folding platform design
    Introduced transverse angle iron members to the folding platform assembly for improved structural support. Updated the platform deck and side angle iron modules to include new mounting holes and adjusted hole positions to align with the transverse angles. Increased side arm length and revised anti-slip hole exclusion zones to accommodate the new structure.
    [lifetrac_v25.scad, platform_deck.scad]
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2025-12-29 Refactor folding platform for parametric, aligned assembly
    Moved folding platform parameters and validation to lifetrac_v25_params.scad for better modularity. Updated all platform components and assembly logic to use new parametric dimensions, ensuring consistent bolt hole alignment and correct fit between angle irons, deck, and pivot brackets. Improved calculation of positions, offsets, and clearances for all platform parts, and updated hardware dimensions and hole patterns for more robust assembly.
    [lifetrac_v25.scad, lifetrac_v25_params.scad, platform_angle_arm.scad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]
2025-12-29 Refine platform geometry calculations in OpenSCAD files
    Updated platform width and pivot X position calculations to align with inner plate faces and ensure correct gaps. Adjusted transverse angle iron length and side angle Z offset logic for more accurate mechanical fit. Improved parameter derivations and assertions for platform assembly.
    [lifetrac_v25.scad, lifetrac_v25_params.scad]
2025-12-29 Revise platform bolt patterns and alignments
    Updated the platform deck, angle iron, and pivot bracket modules to use new bolt patterns and offsets for improved alignment and assembly. Added a third bolt to transverse angles, moved side angle and bracket bolts to new positions with defined offsets, and synchronized hole locations across deck, angle iron, and bracket parts. Introduced new parameters for side gap and bolt offsets in lifetrac_v25_params.scad to ensure consistent spacing and collision avoidance.
    [lifetrac_v25.scad, lifetrac_v25_params.scad, platform_deck.scad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]
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2026-01-03 Correct loader arm tube orientation comments and variables
    Updated comments and variable assignments in the loader_arms module to clarify the orientation of the 2x6 tube, ensuring width and height values match their intended axes.
    [lifetrac_v25.scad]
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2026-01-03 Update loader kinematics and hydraulic cylinder models
    Added calc_kinematics.py for Python-based kinematics calculations. Updated lifetrac_v25_params.scad to use new lift and bucket cylinder parameters, including 16" stroke and revised mounting offsets for improved fit and reach. Adjusted bucket cylinder mount positions and clearances in lifetrac_v25.scad for consistency. Overhauled hydraulics.scad to provide a more detailed and parametric hydraulic cylinder model with accurate pin-to-pin length and geometry.
    [hydraulics.scad, lifetrac_v25.scad, lifetrac_v25_params.scad]
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2026-01-06 Update bucket curl angle and add dump geometry verification
    Changed BUCKET_CURL_MAX_ANGLE from -50 to 45 degrees for correct orientation. Added a section to verify if the cylinder stroke allows for a full vertical dump, with console output for geometry checks and feedback.
    [lifetrac_v25_params.scad]
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2026-01-07 Refactor arm geometry to parametric calculation
    Replaced hardcoded arm dimensions and angles with parametric, geometry-based calculations in lifetrac_v25_params.scad. Updated bucket ground clearance, main arm angle, and related variables to improve accuracy and match user requests. Adjusted animation logic in lifetrac_v25.scad to set default bucket tilt to flat at $t=0.
    [lifetrac_v25.scad, lifetrac_v25_params.scad]
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2026-01-18 Refine bucket and arm plate geometry, add cut coordinate script
    Moved bucket clearance and pivot parameters to lifetrac_v25_params.scad and made them more parametric. Updated arm plate geometry to use new pivot offsets and improved the tip and back corner cut logic. Added test_scripts/calc_cut_coords.py to analyze and verify the cut coordinates for the arm plate extension.
    [arm_plate.scad, lifetrac_v25.scad, lifetrac_v25_params.scad]
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2026-01-20 Fix bucket dump angle to force -45 degrees at full lift
    Updated the animation logic in lifetrac_v25.scad to ensure the bucket reaches a -45 degree dump angle at full lift. Clarified the comment for BUCKET_MIN_CURL_ANGLE in lifetrac_v25_params.scad to indicate it is the target dump angle.
    [lifetrac_v25.scad, lifetrac_v25_params.scad]
2026-01-20 Refactor bucket animation angle calculation
    Reworked the bucket animation logic to interpolate the absolute bucket angle between horizontal at ground and -45 degrees at full lift. Added debug echo statements for animation variables and clarified comments for better maintainability.
    [lifetrac_v25.scad]
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2026-01-25 Refactor lift cylinder geometry and parametric sizing
    Reworked lift cylinder mounting and sizing logic for LifeTrac v25 to use a geometry-first, parametric approach. Cylinder stroke, closed, and extended lengths are now auto-calculated based on arm and base mount positions, with all key parameters and derived values moved to lifetrac_v25_params.scad. Updated lifetrac_v25.scad to use new parametric values, improved verification and debug output, and clarified design principles. Arm plate and loader arm modules now reference integrated hydraulic mounting. Added detailed cylinder analysis documentation and a test script for cylinder sizing.
    [arm_plate.scad, lifetrac_v25.scad, lifetrac_v25_params.scad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]
2026-01-25 Add parametric pivot mount assembly and welding jig
    Introduces a fully parametric, replaceable pivot mount assembly for the loader arm, including new OpenSCAD modules for the assembly, arm plate slot, and bolt pattern. Updates arm plate and loader arm modules to support the new assembly, with non-uniform bolt spacing and proper clearances. Adds a 3D printed welding jig for accurate fabrication. All relevant parameters are centralized in lifetrac_v25_params.scad for consistency and easier modification.
    [arm_plate.scad, lifetrac_v25_params.scad, loader_arm_v2.scad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]
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2026-02-02 Add cross-frame tubes and bottom stiffener
    Add support for 2x6 cross frame tubes and a bottom stiffener plate, including panel cutouts and mounting hardware. Changes include:
    - Insert cross_tube_panel_cutout calls into left/right inner/outer side panels and add bottom-edge trim for inner panels.
    - Add constants and helper functions for bottom plate, horizontal stiffener holes, and frame tube geometry/positioning (FRAME_TUBE_*, FRONT_FRAME_TUBE_Y, REAR_FRAME_TUBE_Y, etc.) and debug echo outputs.
    - Implement horizontal_angle_iron_smart and frame_tube_angle_iron modules and place angle irons for mounting tubes to all wall panels (frame_tube_angle_irons).
    - Add bottom_stiffener_plate module wit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
    [lifetrac_v25.scad]
2026-02-02 Split angle irons, add smart bolt spacing
    Replace fixed hole-placement helpers with smart bolt-spacing functions and split horizontal angle irons into 3 segments with 8" gaps at the wheel axes. Add rotated variant and helper modules for segment holes and plate hole generation; update bottom_stiffener_plate to place segmented angle irons and generate holes per segment. Adjust cross-frame tube placement math to use tube faces (and small trims), trim angle-iron lengths by 1/8" per end, and reduce several bolt spacings from 63.5mm to 50.8mm (5" -> 4"). Add a motor_mounting_plate module and related angle-iron mounts, and propagate angle_len/trim changes into loader_arm_v2 and arm_plate. Includes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
    [arm_plate.scad, lifetrac_v25.scad, loader_arm_v2.scad]
2026-02-03 Add front stiffener plate and motor plate updates
    Introduce a front_stiffener_plate module (geometry, bolt cutouts and trimmed angle-irons) to add the vertical front stiffener flush with the motor mounts; angle irons are shortened to avoid overlap with horizontal angles. Add motor_plate_tube_cutout helper (CNC-friendly corner radius) and integrate 2x6 tube cutouts into motor_mounting_plate. motor_mounting_plate now includes bolt cutouts for frame-tube angle irons and places both the existing horizontal split angles and new vertical frame_tube_angle_iron instances to match tube locations. Finally, call front_stiffener_plate from base_frame so the new plate is included in the assembled frame.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
    [lifetrac_v25.scad]
2026-02-03 Add UWU wheel unit support and frame fixes
    Introduce UWU (Universal Wheel Unit) integration and various frame/fastener updates. Adds a new UWU integration notes file and UWU parameters in lifetrac_v25_params.scad. Update lifetrac_v25.scad with: a show_uwu toggle, new bolt constant (BOLT_DIA_3_8), UWU geometry/parameter echoes, mounting-hole generators (uwu_bearing_holes_2d/3d, uwu_motor_mount_holes), UWU components (bearing, hydraulic motor, shaft, coupling) and full uwu_assemblies/uwu_assembly_positioned implementations. Integrates UWU mounting cutouts into side panels and motor plates, adds shaft/wheel geometry checks and warnings, and makes wheel rendering conditional on the UWU toggle. R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
    [lifetrac_v25.scad, lifetrac_v25_params.scad]
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2026-02-03 Add structural parts and integrate into assembly
    Introduce a new structural parts subsystem and integrate it into the main assembly. Added parts/structural/* modules and a STRUCTURAL_PARTS_CATALOG.md describing angle irons (A1–A10) and tubes (T1–T5) for fabrication-ready parts. lifetrac_v25.scad now imports parts/structural/structural_parts.scad, replaces many inline angle/tube constructs with calls to part_* modules (A1,A2,A4–A10,A5,A6, T1–T3, etc.), adjusts CROSS_BEAM_SPAN calculation, and updates side panel front stiffener trimming to leave a 5" flat section with angled continuation. loader_arm_v2.scad now uses the structural parts library and delegates its arm crossbeam mount to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
    [angle_iron_a10_front_outer.scad, angle_iron_a1_back_outer_vertical.scad, angle_iron_a2_back_inner_vertical.scad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]
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2026-02-16 Add Bobcat wheel hub & rim, update UWU integration
    Introduce Bobcat-compatible wheel/rim/tire and hub geometry and integrate it into the LifeTrac and UWU assemblies.
    Changes:
    - Add new wheel_hub.scad implementing a fabricated hub (DOM tube, triangular gussets, lug plate), simplified Bobcat rim, and skid-steer tire plus bobcat_wheel_assembly for full hub+rim+tire models.
    - Add BOBCAT_* and HUB_* parameters to lifetrac_v25_params.scad (rim, tire, lug pattern, DOM tube and gusset/hub plate parameters) and echo outputs.
    - Replace the previous simple wheel in lifetrac_v25.scad with a Bobcat-style hub+rim+tire assembly and increase wheel_to_wall_clearance from 50.8mm (2") to 76.2mm (3"). Adjust w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
    [lifetrac_v25.scad, lifetrac_v25_params.scad, uwu_v25.scad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]
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2026-04-19 Add UTU variant OpenSCAD assembly
    Add lifetrac_v25_UTU.scad: a tracked (UTU) variant assembly for LifeTrac v25. The file re-derives required parameters, includes/uses the main assembly modules, and implements UTU-specific geometry and modules (extended 2x6 frame tubes, triangular outer bearing mount plates, angle-iron mounts, sprockets, bearings, hydraulic motor, track links and a simplified chain path computation). Replaces the UWU motor mounting plates by using the inner sandwich plate as the motor mount while keeping side panels, stiffeners, loader arms, bucket, hydraulics and folding platform unchanged. Emits echo diagnostics and renders lifetrac_v25_utu_assembly() for review.
    [lifetrac_v25_UTU.scad]
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2026-04-25 Refine UTU chain/plates and idler/drive geometry
    Add TODO note and overhaul UTU OpenSCAD: shift sprocket X to provide wall-to-track gap; expose front/rear idler shift parameters and snap chain loop length to integer links; compute per-sprocket phase angles and echo diagnostics. Introduce an inner idler bearing plate, plate tube cutouts, and angle-iron placements; adjust outer plate color and add frame tube pass-throughs. Update idler/drive axis modules to account for bearing housing lengths, shaft overhangs, and sprocket phase arguments. Rewrite track chain routine to compute full 3-sprocket loop (straight segments + arcs), place links/rods along the loop, and report pitch fit error; derive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
    [lifetrac_v25_UTU.scad]
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2026-04-26 Add example code: base station, bridge, UI
    Add RESEARCH-CONTROLLER/EXAMPLE_CODE prototypes and docs. New files include a base_station stack (lora_bridge.py, web_ui.py, requirements.txt, web/index.html, web/app.js), lora_proto C sources (lora_proto.h, lora_proto.c, crypto_stub.c), handheld and tractor sketches (handheld.ino, tractor_m7.ino, tractor_m4.cpp), opta_modbus_slave.ino, and a top-level EXAMPLE_CODE/README.md. Also update DESIGN-CONTROLLER/LORA_PROTOCOL.md with rationale for not using full MQTT over LoRa, the MQTT-SN-like topic_id scheme, and a tightened TelemetryFrame layout. All code is draft prototype material (for review) and documents KISS framing, AES-GCM usage, and the bridge'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
    [handheld.ino, lora_bridge.py, tractor_m7.ino]
2026-04-26 Apply v25 controller example code review fixes
    Apply fixes from the 2026-04-26 pipeline code review to make the example controller chain internally consistent and safer for bench testing. Key changes:
    - Add code-review notes and a CODE_REVIEW_FIXES.md summary; update README to mark the review pass.
    - Make ControlFrame truly 16 bytes: add reserved byte in lora_proto.h and set it in lora_proto.c/web_ui.py; update LORA_PROTOCOL.md table and packers.
    - Fix handheld nonce/sequence bug: ensure the same sequence value is used in the header and AES-GCM nonce; add axis deadband and button debounce.
    - Add build guard to crypto_stub.c to prevent accidental insecure builds (require LIFETRAC_ALLOW_STUB_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
    [handheld.ino, lora_bridge.py, tractor_m7.ino]
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2026-04-27 Update Arduino CI and add base-station tests
    Revise the GitHub Actions workflow to focus on active DESIGN-CONTROLLER/firmware, base_station and tools: replace prior Arduino compile jobs for archived sketches with a Python unittest gate for base_station and a non-blocking firmware compile status step. Add workspace files and tooling: .vscode settings, .gitignore entry to exclude local LoRa key.h, new base_station Python modules and tests (lora_proto.py, link_monitor.py, lora_bridge.py + tests), provisioning/tools, and a bench sketch. Update many DESIGN-CONTROLLER docs (ARCHITECTURE, LORA_IMPLEMENTATION, LORA_PROTOCOL, ARDUINO_CI, BASE_STATION, etc.) to reflect the current implementation, CI g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
    [handheld.ino, link_monitor.py, lora_bridge.py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]
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2026-04-28 Add best-effort firmware CI and bridge security
    Add best-effort arduino-cli CI jobs for handheld_mkr, tractor_opta and tractor_h7 (continue-on-error, stage shared sources into sketch/src, install cores/libs, compile with/without real crypto). Harden base_station lora_bridge: load/validate AES-128 fleet key from LIFETRAC_FLEET_KEY_FILE or LIFETRAC_FLEET_KEY_HEX and refuse to start on misconfig; integrate NonceStore for persistent nonce sequencing; add TelemetryReassembler for fragmented telemetry; restamp control frames with bridge-owned sequence numbers; subscribe/emit req_keyframe topic; take an exclusive flock to prevent concurrent bridge instances. Add DESIGN-CONTROLLER/.gitignore for sec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
    [handheld_mkr.ino, lora_bridge.py, lora_proto.py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]
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2026-04-29 Enhance Arduino CI, add firmware tests & docs
    Revamp the Arduino CI to make key firmware compiles blocking and more robust: stage shared sources into sketch src/ folders, switch to compiler.{c,cpp}.extra_flags for additive defines, add explicit allow/real-crypto flags, install missing Opta library, and add a new M4 co-processor compile job. Add CI/workflow comments documenting rounds of fixes and why staging/flags were needed. Add many unit tests and test harnesses for base_station (telemetry, fragmentation, replay, fuzzing, concurrency) plus HIL_RUNBOOK, staging script, and other tooling; update web_ui.py and tests to address websocket/admission and audit issues. Rename/organize firmware sk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
    [handheld_mkr.ino, tractor_h7.ino, tractor_h7_m4.ino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]
2026-04-29 Add Wave-4 SIL tests, HIL scripts, and Arduino fixes
    Add a large batch of Wave-4 SIL/HIL assets and CI helper scripts to expand verification coverage and unblock Arduino compile gates. New files: multiple base_station SIL tests (axis_ramp, boot_phy, fleet_key_provisioning, hil_harness_completeness, keyframe_round_trip, link_tune, mqtt_retry_backoff, nonce_seq_threadthrough, protocol_constants, and others), HIL PowerShell scripts and README, results_schema.json, MASTER_TEST_PROGRAM.md, and various test modules for control/telemetry/image fragmentation, M4 safety, and Modbus slave SILs. Modified files: updated LifeTrac-v25/TODO.md and AI NOTES to reflect progress; updated firmware/handheld_mkr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
    [handheld_mkr.ino]
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2026-05-08 L072 bring-up: notes, build targets, Method G tools
    Add extensive L072 bring-up artifacts and Method G tooling. Includes multiple AI NOTES documenting radio minimizer/power-cycle policy, hello-world build/flash logs, AT parser findings, and Method G power-cycle avoidance (v1/v2). Introduce a hello build target and artifacts for murata_l072 (hello_world.c, build outputs, linker/ld files) and update Makefile to support the hello target. Update register header (stm32l072_regs.h) and LoRa protocol files; adjust bench/crypto host_check and stm32 flasher tooling. Add x8_lora_bootloader_helper scripts (prep_bridge.sh, revive_bridge.sh, wdt_pet.sh, full_flash_pipeline.sh and helpers) plus test scrip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
    [fix_pa9.cfg, poke_pa9.cfg]
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

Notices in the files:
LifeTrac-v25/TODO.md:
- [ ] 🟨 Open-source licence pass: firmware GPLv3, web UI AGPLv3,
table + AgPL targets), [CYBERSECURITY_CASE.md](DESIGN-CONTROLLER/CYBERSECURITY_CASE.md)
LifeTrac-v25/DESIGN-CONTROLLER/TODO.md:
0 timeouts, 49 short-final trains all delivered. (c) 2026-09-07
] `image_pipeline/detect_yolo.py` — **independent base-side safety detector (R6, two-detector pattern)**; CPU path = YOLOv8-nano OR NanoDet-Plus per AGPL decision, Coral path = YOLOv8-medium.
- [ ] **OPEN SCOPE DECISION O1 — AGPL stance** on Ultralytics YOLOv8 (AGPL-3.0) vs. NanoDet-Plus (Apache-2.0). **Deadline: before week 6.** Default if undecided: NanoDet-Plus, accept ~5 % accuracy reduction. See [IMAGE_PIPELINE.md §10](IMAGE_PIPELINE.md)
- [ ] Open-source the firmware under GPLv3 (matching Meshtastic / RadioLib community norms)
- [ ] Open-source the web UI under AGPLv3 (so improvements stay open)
